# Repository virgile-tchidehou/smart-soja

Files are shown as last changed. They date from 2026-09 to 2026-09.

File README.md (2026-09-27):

<div align="center">

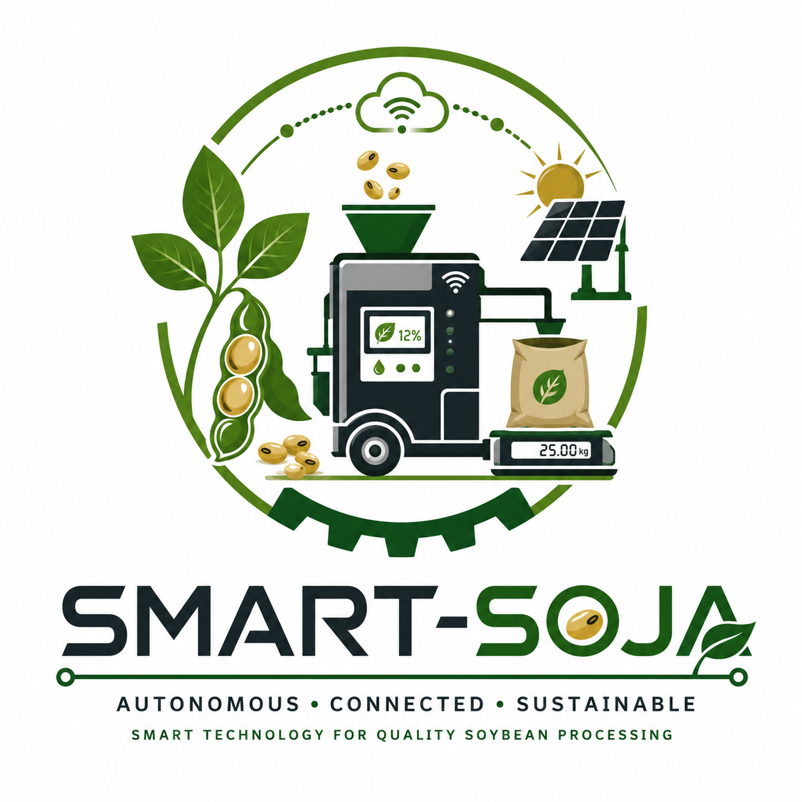
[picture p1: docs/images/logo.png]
SMART-SOJA logo


# 🌱 SMART-SOJA

### An Autonomous IoT-Based Mobile Soybean Pre-processing System














**[Documentation](#-documentation) · [Architecture](#️-system-architecture) · [Hardware](#️-hardware-overview) · [Roadmap](#-project-roadmap)**

</div>

---

SMART-SOJA is an academic engineering project co-developed by **Elisa Christelle LOKO** and **Dodji Virgile TCHIDEHOU**. It explores a mobile and connected soybean pre-processing unit designed to improve post-harvest handling in rural environments.

The prototype combines embedded systems, industrial automation, IoT technologies and an off-grid solar/battery architecture. At its current stage, the project is a **functional proof of concept**: the main sensing, actuation, drying and IoT subsystems have been validated individually or in partial integration, while full-cycle validation under a real 2–5 kg load and final HX711 weighing integration remain future work.

<div align="center">
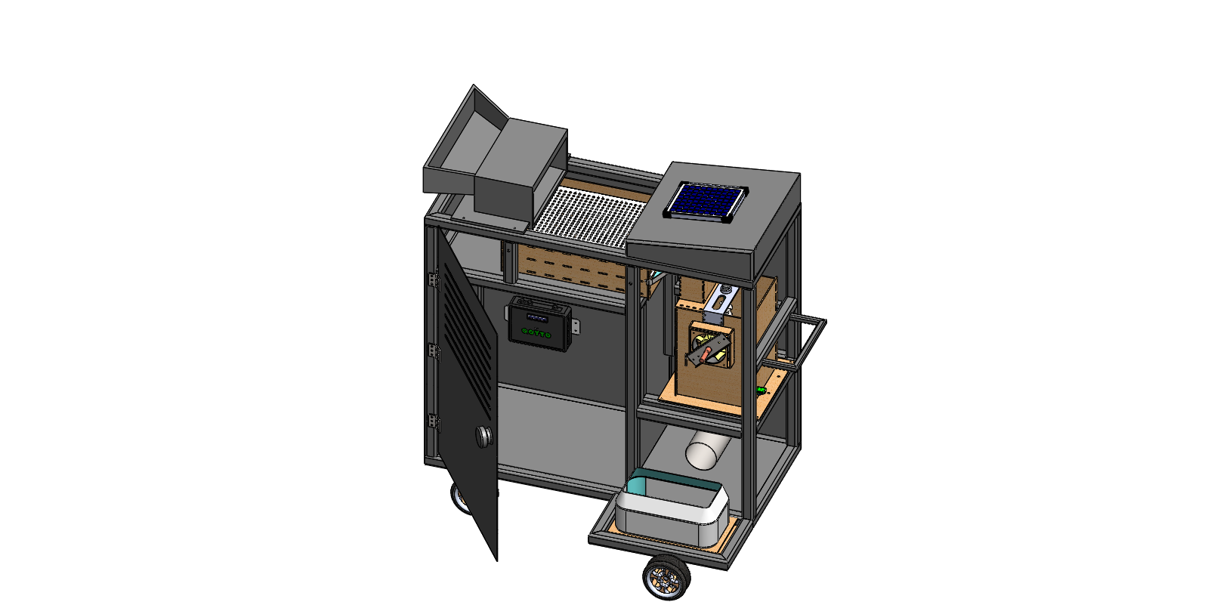
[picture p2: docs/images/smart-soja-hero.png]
SMART-SOJA prototype — assembled 3D view

</div>

---

## 📖 Table of Contents

- Overview
- The Problem
- Objectives
- Key Features
- System Architecture
- Hardware Overview
- Software Architecture
- Technology Stack
- Repository Structure
- Documentation
- Roadmap
- Future Improvements
- Project Team
- License

---

# 📌 Overview

Soybean production is rapidly increasing across Africa, particularly in Benin. However, post-harvest losses caused by inadequate cleaning, excessive moisture and poor traceability continue to reduce product quality and market value.

SMART-SOJA addresses these challenges by providing a mobile cyber-physical system capable of:

- Cleaning soybean grains through a vibrating sieve mechanism
- Measuring grain moisture at two points
- Controlling an active drying subsystem
- Supporting final batch weighing through an HX711-based subsystem *(final integration pending)*
- Recording production data locally
- Synchronizing traceability data through MQTT

The project integrates mechanical engineering, embedded electronics, industrial automation and cloud connectivity into a single modular platform.

---

# ❗ The Problem

Smallholder farmers often face several challenges:

- High post-harvest losses
- Non-uniform drying
- Manual quality control
- Lack of digital traceability
- Limited access to electricity

SMART-SOJA was designed to provide an affordable and intelligent solution adapted to rural environments.

---

# 🎯 Objectives

The project aims to:

- automate soybean pre-processing;
- improve grain quality before storage;
- reduce moisture-related losses;
- provide digital traceability;
- support off-grid operation through a solar/battery power architecture;
- support smart agriculture initiatives.

---

# ✨ Key Features

- 🌱 Mobile modular platform
- 📡 IoT connectivity using MQTT
- ⚙️ Embedded control with ESP32
- ☀️ Solar/battery off-grid power architecture
- 💧 Dual moisture sensing
- 🔥 Active drying control
- ⚖️ HX711-based weighing subsystem *(final integration pending)*
- 💾 Offline data logging (MicroSD)
- ☁️ Cloud synchronization
- 📊 Real-time monitoring
- 🧠 FreeRTOS multitasking architecture
- 🔄 GRAFCET-based sequential control

---

# 🏗️ System Architecture

SMART-SOJA is composed of six major subsystems:

## Mechanical System

- Modular chassis
- Cleaning mechanism
- Drying chamber
- Weighing module
- Mobile structure

## Embedded Electronics

- ESP32 microcontroller
- Sensors
- Power electronics
- Human-Machine Interface

## Energy System

- Solar panel
- Battery
- Charging controller
- DC converters

## Control System

- FreeRTOS scheduler
- GRAFCET automation
- Safety management

## IoT Layer

- MQTT communication
- JSON data exchange
- Cloud synchronization
- Store-and-Forward mechanism

## Traceability Layer

- Batch identification
- Local storage
- Cloud database
- Digital production records

---

# ⚙️ Hardware Overview

Main components include:

- ESP32 DevKit
- Capacitive moisture sensors
- HX711 load cell module
- Servo motors
- DC geared motors
- MOSFET power drivers
- LCD I2C display
- MicroSD module
- Solar panel
- Battery system

---

# 💻 Software Architecture

The embedded firmware is based on FreeRTOS.

Main software modules:

- Safety Task
- Control Task
- Sensor Task
- Actuator Task
- LCD Task
- MQTT Task

The control logic is modeled using a two-level GRAFCET to ensure deterministic and reliable operation.

---

# 🛠️ Technology Stack

## Embedded

- ESP32
- FreeRTOS
- Arduino IDE / Arduino Framework

## IoT

- MQTT (HiveMQ broker)
- JSON
- Wi-Fi

## Cloud & Web

- Node.js / Express (MQTT-to-cloud bridge API)
- Firebase (Firestore, Realtime Database, Hosting)
- Vite.js / Vanilla JavaScript (dashboard SPA)

## Mechanical

- SolidWorks

## Electronics

- KiCad

---

# 📁 Repository Structure

```text
smart-soja/
│
├── README.md                  # Présentation du projet
├── LICENSE
├── .gitignore
│
├── docs/                       # Documentation technique (9 chapitres + images)
│   ├── 01-project-overview.md
│   ├── 02-system-architecture.md
│   ├── 03-hardware-design.md
│   ├── 04-mechanical-design.md
│   ├── 05-software-architecture.md
│   ├── 06-energy-system.md
│   ├── 07-testing-validation.md
│   ├── 08-results.md
│   ├── 09-future-improvements.md
│   └── images/
│
├── firmware/
│   └── esp32/
│       └── src/                # Firmware ESP32 (FreeRTOS, GRAFCET)
│
├── hardware/                   # Conception électronique (KiCad)
│   ├── conception.md
│   ├── pcb/circuit_smart-soja/ # Projet KiCad complet (sch, pcb, gerbers, BOM)
│   ├── schematics/              # Exports PDF/SVG du schéma
│   ├── bom/                     # Nomenclature des composants
│   ├── wiring/                  # Schémas de brochage (pinout) des capteurs/modules
│   └── datasheets/               # Références vers les fiches techniques constructeur
│
├── mechanical/                 # Conception mécanique (SolidWorks)
│   ├── conception.md
│   ├── solidworks/
│   ├── stl/
│   ├── drawings/
│   └── renders/
│
├── cloud/
│   ├── mqtt/                   # Spécification du protocole ESP32 ↔ broker
│   ├── database/                # Documentation du schéma Firestore
│   ├── api/                     # Backend Node.js/Express (passerelle MQTT → Firebase)
│   └── dashboard/app/           # Plateforme web Vite.js (tableaux de bord)
│
├── media/                      # Photos du prototype, captures d'écran, diagrammes
│   ├── prototype/
│   ├── screenshots/
│   └── diagrams/
│
├── research/
│   └── thesis/                  # Mémoire complet (source de la documentation)
│
└── .github/
    └── ISSUE_TEMPLATE/
```

---

# 📚 Documentation

Full technical documentation lives in [`docs/`](docs/):

| Chapter | Content |
|---|---|
| [01 – Project Overview](docs/01-project-overview.md) | Context, problem statement, objectives |
| [02 – System Architecture](docs/02-system-architecture.md) | Edge / Cloud / Application layers |
| [03 – Hardware Design](docs/03-hardware-design.md) | ESP32, sensors, actuators, PCB |
| [04 – Mechanical Design](docs/04-mechanical-design.md) | Modular chassis and 4 functional blocks |
| [05 – Software Architecture](docs/05-software-architecture.md) | FreeRTOS, GRAFCET, MQTT/JSON, web dashboard |
| [06 – Energy System](docs/06-energy-system.md) | Solar/battery sizing |
| [07 – Testing & Validation](docs/07-testing-validation.md) | Unit test protocol and results |
| [08 – Results](docs/08-results.md) | Prototype outcomes, financial evaluation |
| [09 – Future Improvements](docs/09-future-improvements.md) | Validation roadmap and product evolution |

The technical documentation in this repository is derived from the academic thesis. The full thesis PDF is intentionally not distributed in the public repository; supporting figures and project material remain under [`research/thesis/`](research/thesis/).

---

# 🚀 Project Roadmap

- [x] Problem identification
- [x] Requirements analysis
- [x] Mechanical design
- [x] Electronic architecture
- [x] Embedded software
- [x] Prototype assembly and integration
- [x] Unit-level functional validation (sensors, actuators, MQTT traceability)

### Next Milestones

- [ ] Full clean + dry cycle validation under real load (2–5 kg)
- [ ] Load-cell (HX711) weighing module integration
- [ ] Field testing under real environmental conditions
- [ ] PCB redesign (multilayer)
- [ ] Mobile application
- [ ] OTA firmware updates
- [ ] AI-assisted moisture prediction
- [ ] Version 2 prototype

---

# 🌍 Future Vision

SMART-SOJA is envisioned as a scalable smart agriculture platform capable of supporting digital transformation in African agricultural value chains.

Future versions will integrate:

- Edge AI
- Predictive maintenance
- Computer vision
- Fleet management
- Remote diagnostics
- Industrial IoT deployment

---

<div align="center">

# 👥 Project Team

**Elisa Christelle LOKO** — Co-developer  
**Dodji Virgile TCHIDEHOU** — Co-developer · repository maintainer

Final-year project — Professional License in Industrial Computing & Maintenance, EGEI / UCAO-UUC, 2026.  
Academic supervisor: **Dr DIDAVI Audace**

This public repository is maintained by Dodji Virgile TCHIDEHOU and documents the team project together with the technical work contributed during its development.



</div>

---

# 📄 License

<div align="center">

This project is licensed under the [MIT License](LICENSE).

**🌱 SMART-SOJA — from the field to the factory, one certified batch at a time.**

</div>

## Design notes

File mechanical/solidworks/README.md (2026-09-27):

# SolidWorks source files

Le modèle CAO complet (assemblage final `Smart-Soja.STEP` ainsi que les pièces et sous-assemblages SolidWorks détaillés) n'est pas distribué dans ce dépôt public.

Pour consulter les rendus et vues techniques, voir [`mechanical/renders/`](../renders/) et [`mechanical/drawings/`](../drawings/), ainsi que [04-mechanical-design.md](../../docs/04-mechanical-design.md).

Pour un accès aux fichiers sources, contacter le mainteneur du dépôt — voir la section [Project Team](../../README.md#-project-team) du README.

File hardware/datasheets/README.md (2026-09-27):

# Datasheets

Aucune fiche technique constructeur n'est redistribuée dans ce dépôt (droits d'auteur des fabricants). Références des composants utilisés par SMART-SOJA :

| Composant | Fabricant / réf. | Datasheet |
|---|---|---|
| ESP32-WROOM-32 | Espressif | https://www.espressif.com/en/products/modules/esp32 |
| DHT22 (AM2302) | Aosong | https://www.adafruit.com/product/385 |
| HX711 (amplificateur cellule de charge) | Avia Semiconductor | https://www.sparkfun.com/products/13879 |
| MOSFET IRLZ44N | Infineon / Vishay | https://www.vishay.com/docs/91238/irlz44n.pdf |
| Régulateur LM2596 | Texas Instruments | https://www.ti.com/product/LM2596 |
| Servomoteur SG90 | Tower Pro | https://www.towerpro.com.tw/product/sg90-7/ |
| Moteur DC JGA25-370 | générique | voir revendeur |

Voir aussi [`hardware/wiring/`](../wiring/) pour les schémas de brochage (pinout) utilisés lors de l'intégration.

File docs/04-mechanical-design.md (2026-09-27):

# Mechanical Design

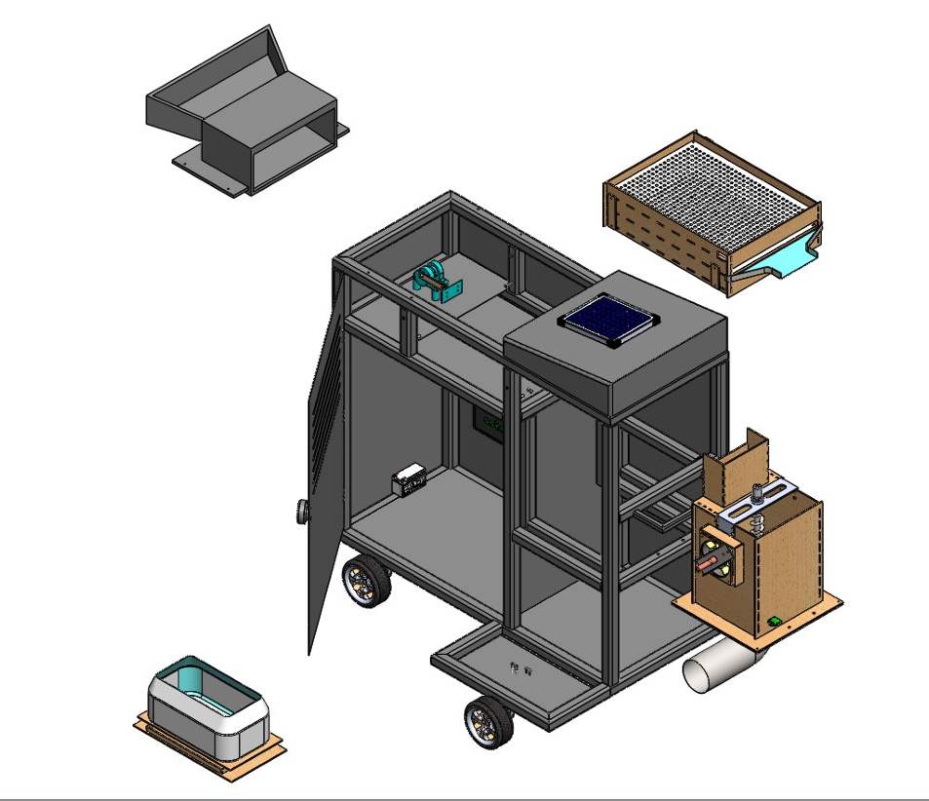
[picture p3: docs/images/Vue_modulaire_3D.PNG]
Vue modulaire 3D


Rendus et plans : [`mechanical/renders/`](../mechanical/renders/), [`mechanical/stl/`](../mechanical/stl/) (impression 3D), [`mechanical/drawings/`](../mechanical/drawings/) (découpe laser, mises en plan). Document de conception détaillé : [`mechanical/conception.md`](../mechanical/conception.md).

> Le dépôt étant public, les fichiers CAO SolidWorks (assemblage final et pièces détaillées) ne sont pas distribués ici — voir [`mechanical/solidworks/README.md`](../mechanical/solidworks/README.md) pour les obtenir sur demande.

## Architecture modulaire

La conception mécanique repose sur un **châssis porteur** (acier, tubes 30–40 mm) accueillant **quatre blocs fonctionnels amovibles**, montés sur glissières et connecteurs rapides afin de permettre une maintenance en milieu rural isolé sans démontage intégral (retrait/repose d'un bloc en moins de 15 min).

| Bloc | Fonction |
|---|---|
| **Bloc 1 — Entrée** | Trémie pyramidale à écoulement gravitaire, vanne pilotée par servomoteur SG90, capteur IR1 de présence de soja |
| **Bloc 2 — Nettoyage / tamisage** | Deux tamis inox superposés sur suspensions élastiques, moteur JGA25-370 entraînant les oscillations via poulie/tige de transmission |
| **Bloc 3 — Séchage / analyse** | Vis sans fin (brassage), ensemble ventilateur + résistance chauffante, boîtiers pour sondes capacitives Soil1/Soil2 et DHT22 |
| **Bloc 4 — Pesée / réception** | Support cellule de charge (HX711), plateau de réception finale, capteur IR2 de retrait du sac |

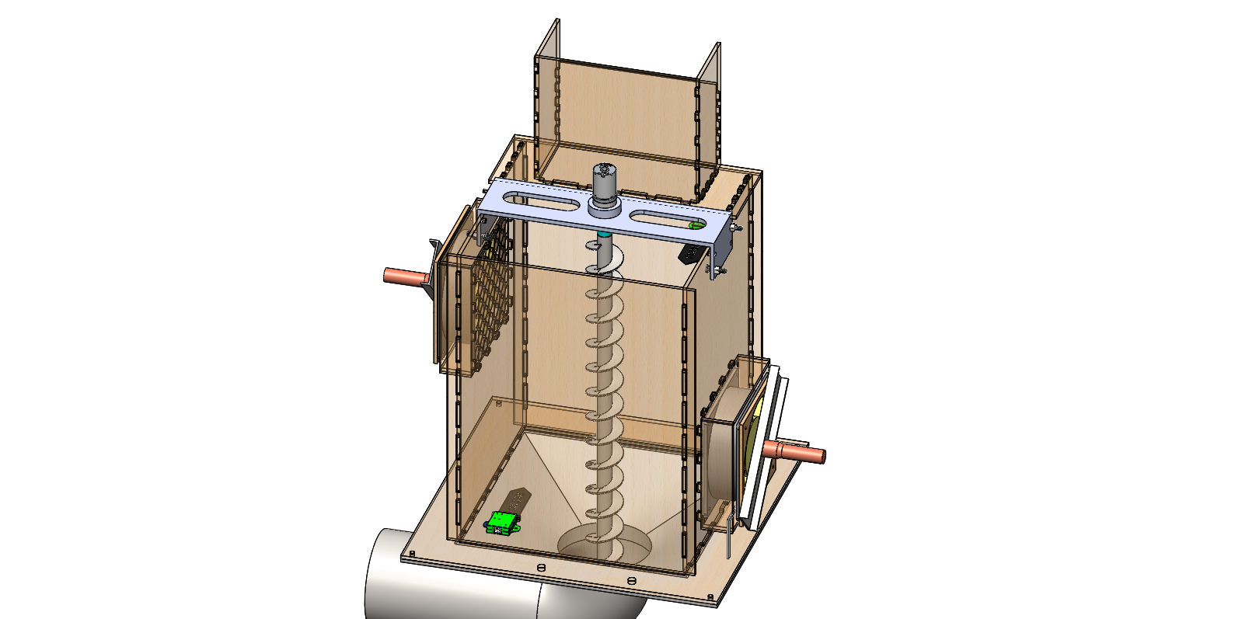
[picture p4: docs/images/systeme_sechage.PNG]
Système de séchage

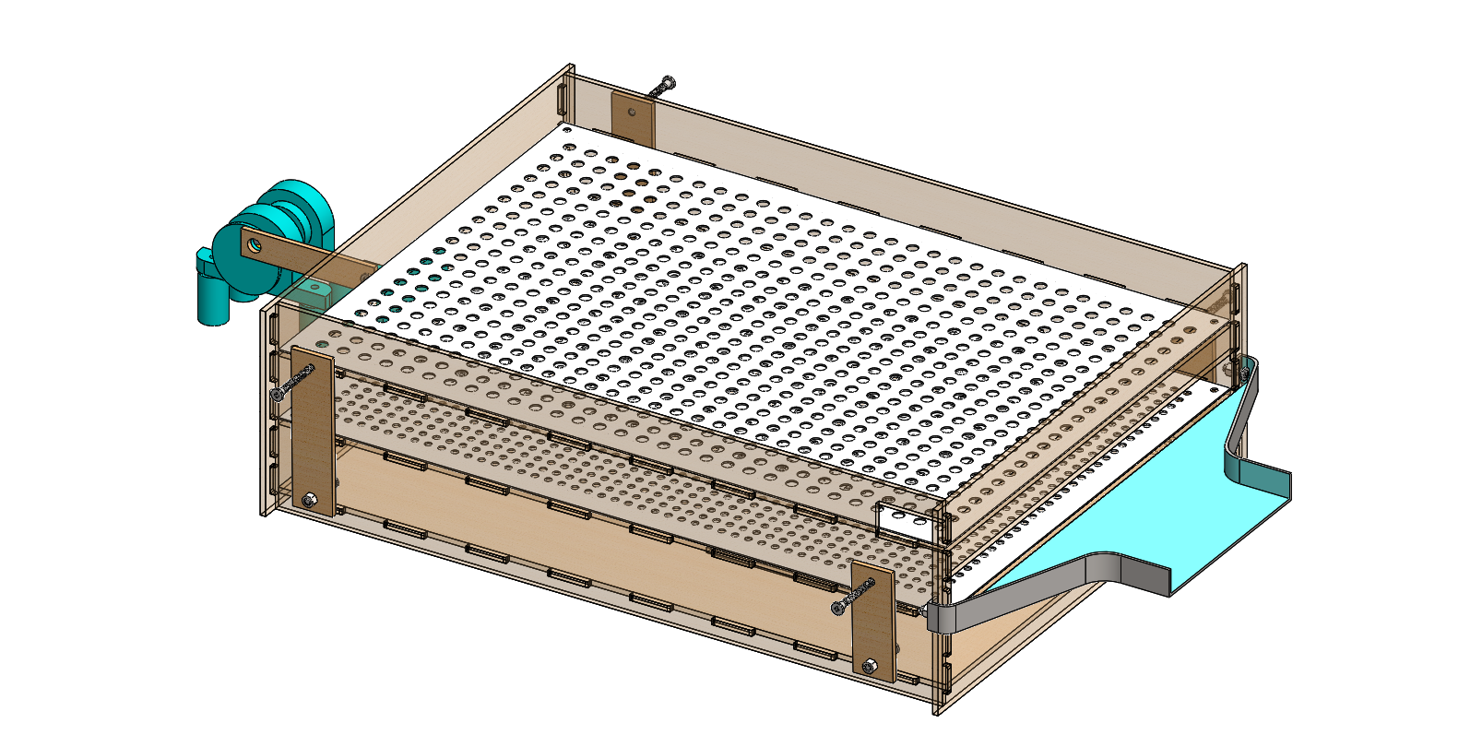
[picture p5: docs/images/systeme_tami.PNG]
Système de tamisage


## Matériaux

| Élément | Masse (kg) | Contrainte | Justification |
|---|---|---|---|
| Châssis porteur | 12,0 | Compression / haute | Acier (tubes 40 mm) : robustesse et soudabilité |
| Support tamis | 0,293 | Vibration / haute | Inox 304 : résistance à la corrosion et hygiène |
| Support capteur | 0,1 | Flexion / moyenne | PLA (impression 3D) : précision et légèreté |
| Roulettes (×4) | 2,0 | Chocs / élastique | Caoutchouc HD : absorption des vibrations |

## Outils de conception

- **SolidWorks** — modélisation 3D intégrale, simulation d'assemblage, mises en plan techniques.
- **KiCad** — conception du PCB embarqué (voir [03-hardware-design.md](03-hardware-design.md)).

## Fabrication et assemblage

Le châssis a été réalisé par découpe de panneaux de contreplaqué haute densité, aux dimensions issues de la modélisation SolidWorks, à l'atelier de **Sèmè City Open Park** (scie circulaire sur table).

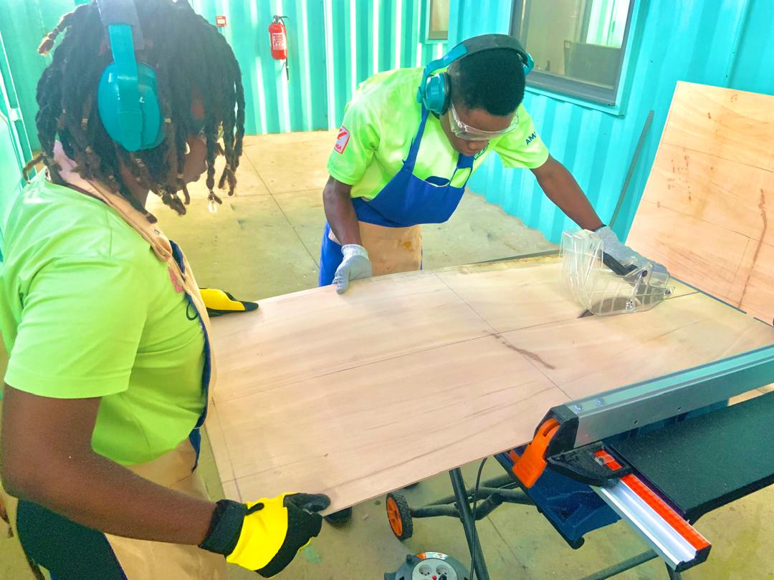
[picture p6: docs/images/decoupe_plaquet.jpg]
Découpe du contreplaqué


Le prototype physique assemblé (juin 2026) est visible ci-dessous — blocs d'alimentation, de tamisage et de séchage :

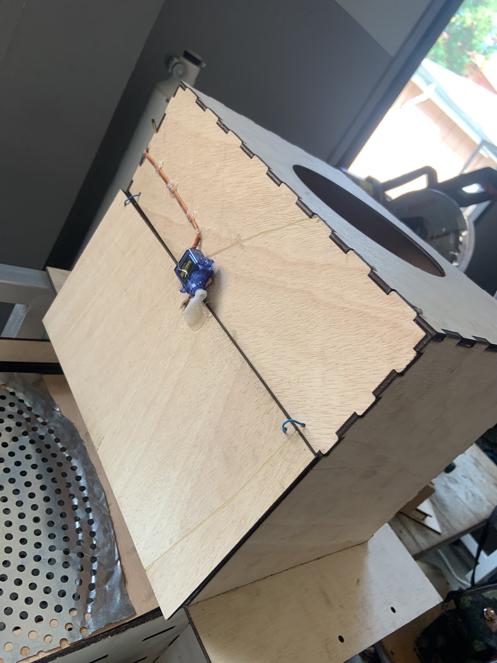
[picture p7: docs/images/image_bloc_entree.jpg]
Bloc d'alimentation

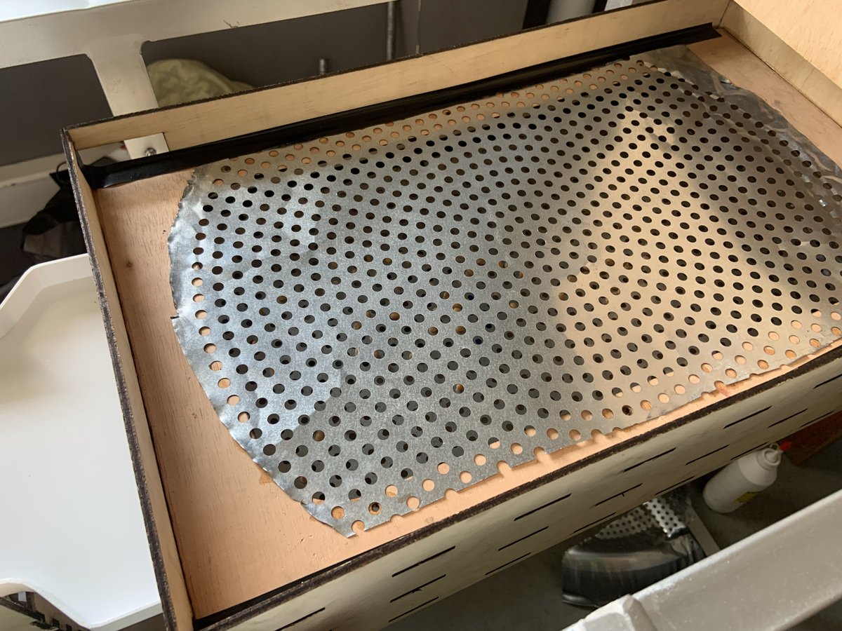
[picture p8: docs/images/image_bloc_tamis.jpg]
Bloc de tamisage

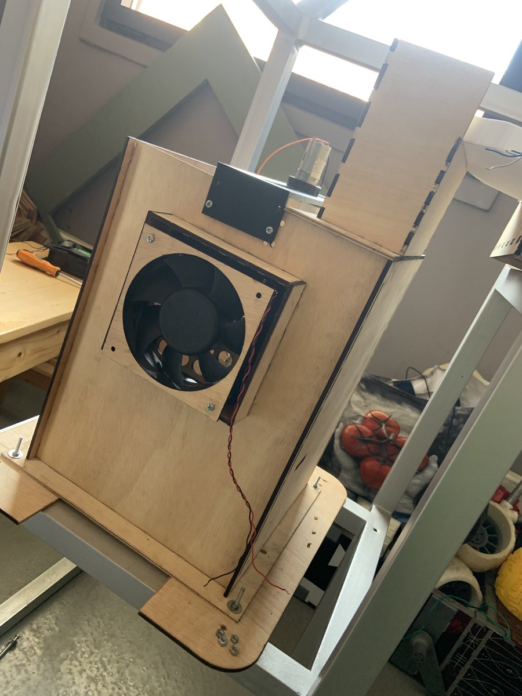
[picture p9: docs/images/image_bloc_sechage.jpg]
Bloc de séchage


## Voir aussi

- [`mechanical/drawings/`](../mechanical/drawings/) — DXF pour découpe laser, mise en plan (`Mise_en_plan_Smart-Soja.SLDDRW`)
- [`mechanical/stl/`](../mechanical/stl/) — pièces imprimables en 3D
- [07-testing-validation.md](07-testing-validation.md) — validation du tamisage et du séchage

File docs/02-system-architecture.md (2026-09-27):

# System Architecture

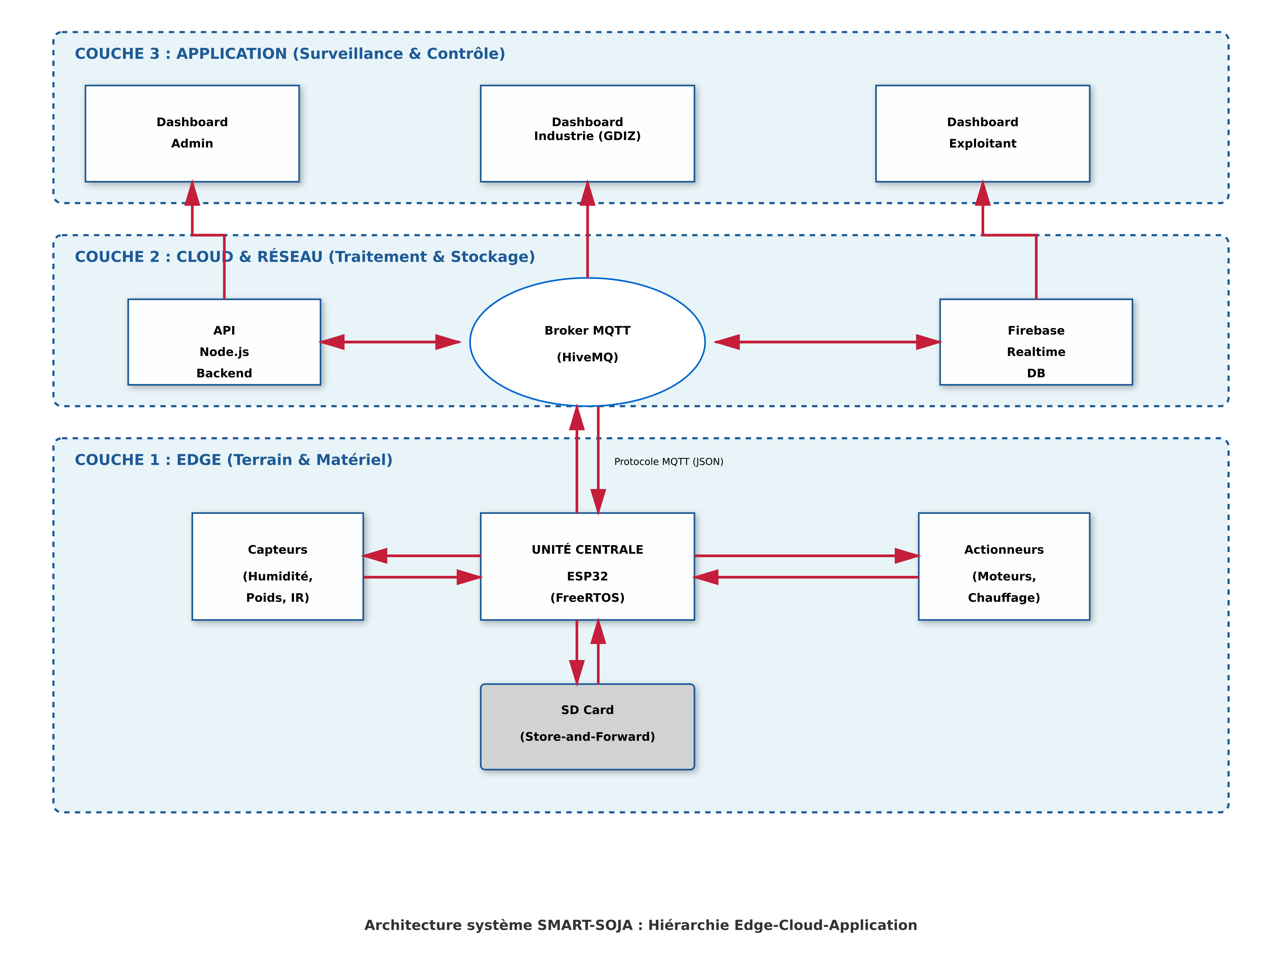
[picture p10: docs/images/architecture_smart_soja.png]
Architecture SMART-SOJA


SMART-SOJA repose sur une architecture modulaire hiérarchisée en **trois couches fonctionnelles**, garantissant un fonctionnement autonome complet en mode déconnecté tout en s'intégrant nativement dans une infrastructure Cloud de type Industrie 4.0.

## Couche Edge (terrain)

L'**ESP32** gère en temps réel :
- l'acquisition des capteurs (humidité, température, présence, poids) ;
- le pilotage des actionneurs (moteurs, résistance, ventilateur, servomoteurs) ;
- la logique de contrôle séquentiel **GRAFCET** ;
- la sécurité prioritaire (arrêt d'urgence, surchauffe).

Détails : [05-software-architecture.md](05-software-architecture.md).

## Couche Cloud

- **Broker MQTT (HiveMQ)** : réception des trames télémétrie et fin-de-lot publiées par l'ESP32.
- **API Node.js (`cloud/api/`)** : passerelle qui intercepte les messages MQTT, les valide, les enregistre dans Firebase et génère les documents de traçabilité (QR Code, PDF).
- **Firebase (Firestore + Realtime Database)** : stockage persistant des lots traités.

## Couche Application

- **Tableau de bord web (`cloud/dashboard/app/`)** : Single Page Application (Vite.js + JavaScript) avec trois profils d'accès :
  - **Exploitant** : suivi de production temps réel, contrôle manuel des actionneurs via MQTT, alertes maintenance ;
  - **Industrie (GDIZ Ready)** : validation qualité des lots entrants, graphiques humidité/température, certificats de traçabilité PDF ;
  - **Admin** : gestion de la flotte de machines et des utilisateurs.

## Résilience réseau : Store-and-Forward

En l'absence de couverture WiFi (fréquente en zone rurale), toutes les métriques sont sauvegardées localement sur carte MicroSD (SPI, FAT32) et retransmises automatiquement au broker MQTT dès la reconnexion. Ce mécanisme garantit qu'aucune donnée de traçabilité n'est perdue.

## Flux de données

```mermaid
flowchart LR
    subgraph Edge["Couche Edge (ESP32)"]
        S[Capteurs] --> C[GRAFCET / FreeRTOS]
        C --> A[Actionneurs]
        C --> SD[MicroSD - Store & Forward]
    end
    C -- JSON / MQTT --> B[Broker MQTT HiveMQ]
    B --> API[API Node.js - cloud/api]
    API --> FB[(Firebase Firestore)]
    FB --> WEB[Dashboard Web - cloud/dashboard/app]
```

## Voir aussi

- [03-hardware-design.md](03-hardware-design.md)
- [04-mechanical-design.md](04-mechanical-design.md)
- [../cloud/mqtt/ESP32_PROTOCOL.md](../cloud/mqtt/ESP32_PROTOCOL.md) — spécification détaillée des topics et payloads MQTT

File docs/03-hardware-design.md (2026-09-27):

# Hardware Design

Fichiers sources : [`hardware/pcb/circuit_smart-soja/`](../hardware/pcb/circuit_smart-soja/) (projet KiCad complet), [`hardware/bom/`](../hardware/bom/), [`hardware/schematics/`](../hardware/schematics/). Document de conception détaillé : [`hardware/conception.md`](../hardware/conception.md).

## Unité de traitement : ESP32-WROOM-32

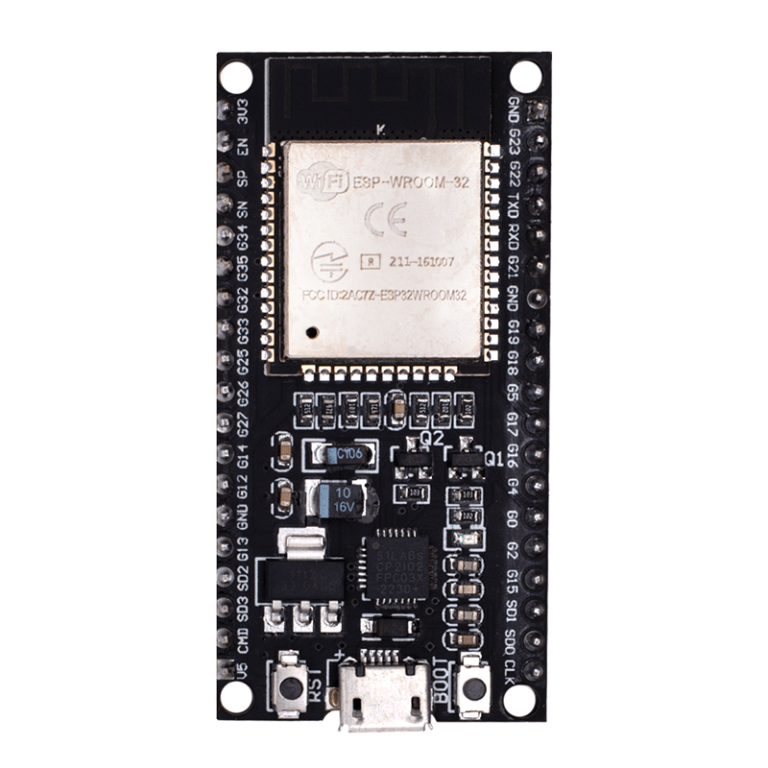
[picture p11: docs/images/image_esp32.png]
ESP32


| Caractéristique | Spécification |
|---|---|
| Microcontrôleur | Tensilica LX6 double cœur, 240 MHz |
| Alimentation | 5 V DC (microUSB) / 3,3 V DC (E/S) |
| Consommation veille | 5 µA |
| Mémoire | 520 Ko SRAM / 4 Mo Flash |
| Connectivité | Wi-Fi 802.11 b/g/n + Bluetooth 4.2 |
| GPIO | 30 broches (3× UART, 2× I2C, 3× SPI, 12× ADC, 2× DAC) |

**Justification :** l'architecture dual-core dédie un cœur au contrôle-commande temps réel (capteurs, PWM) et l'autre à la communication IoT (MQTT/WiFi), garantissant un déterminisme critique. Le brochage évite les *strapping pins* (GPIO 0, 2, 12, 15) critiques au démarrage.

## Chaîne d'acquisition (capteurs)

| Capteur | Plage / Précision | Rôle | Limites |
|---|---|---|---|
| DHT22 | 0–100 % HR / ±2 % | Humidité/température ambiante | Temps de réponse 2 s |
| Sonde capacitive (×2, Soil1/Soil2) | 0–100 % / ±5 % | Humidité des grains | Dérive thermique |
| IR réflectif (×2) | 2–30 cm / binaire | Présence trémie/sac | Sensible à la lumière ambiante |
| Cellule de charge + HX711 | 0–10 kg / ±0,1 % | Pesée finale du lot | Sensible aux vibrations |

La sonde capacitive mesure la constante diélectrique du milieu (eau ≈ 80 vs grain sec ≈ 3–5), ce qui la rend insensible à la corrosion. Deux sondes (haut/bas de la zone de séchage) permettent une double validation : le séchage ne s'arrête que si **Soil1 ET Soil2 ≤ 12 %**.

**Calibration in-situ** (ADC 12 bits, 0–4095) : point sec (H ≈ 8 %, soja étuvé) comme borne haute, point humide (H ≈ 20 %) comme borne basse, puis interpolation linéaire. Écart maximal observé face à un hygromètre de référence (Testo 608-H2) : ±5 %.

## Chaîne d'action (actionneurs)

| Actionneur | Puissance / Courant | Rôle |
|---|---|---|
| Moteurs JGA25-370 (×2) | 3 W / 0,5 A (max 1,2 A) | Tamisage, vis sans fin |
| Servo SG90 (×2) | 1,5 W / 0,1–0,5 A | Vanne trémie |
| Résistance chauffante (×2) | 12 W / 1 A | Séchage |
| Ventilateur DC (×2) | 1,8 W / 0,15 A | Circulation d'air |
| MOSFET IRLZ44N (×4) | *Logic level*, 47 A max, R<sub>DSon</sub> 0,022 Ω | Commutation 12 V depuis GPIO 3,3 V |

Le MOSFET **IRLZ44N** est retenu car il se sature directement avec les 3,3 V de l'ESP32 (contrairement aux MOSFET standards qui exigent 10 V de grille).

## Interfaces homme-machine et traçabilité locale

| Périphérique | Protocole | Rôle |
|---|---|---|
| LCD 16×2 | I2C | Affichage temps réel |
| Lecteur MicroSD | SPI | Store-and-Forward |
| Potentiomètres ×2 | ADC 12 bits | Réglage vitesse moteurs |
| Boutons ON/OFF | GPIO pull-up | Démarrage/arrêt sécurisé |
| LEDs + buzzer | Digital/PWM | Signalisation d'état |

## Circuit imprimé (PCB)

Le circuit est segmenté en cinq zones fonctionnelles pour limiter les interférences électromagnétiques entre signaux de puissance et de commande :

1. **Zone alimentation** — régulateur Buck LM2596 (12 V → 5 V/2 A) ; logique 3,3 V via le régulateur interne de l'ESP32.
2. **Zone ESP32** — affectation des broches optimisée pour éviter les strapping pins.
3. **Zone puissance** — chaque canal MOSFET IRLZ44N intègre une résistance de grille 220 Ω, un pull-down 10 kΩ, et une diode de roue libre 1N5408 contre les retours inductifs.
4. **Zone acquisition** — signaux analogiques (sondes capacitives sur GPIO 36/39) et numériques (HX711 sur GPIO 25, DHT22, IR sur GPIO 32/33).
5. **Zone IHM** — bus I2C (LCD), bus SPI (SD), signaux PWM (buzzer, servo, boutons).

Routage sur **une seule couche** (face inférieure) avec pistes de puissance ≥ 1 mm et plan de masse (ground pour) pour simplifier la fabrication du prototype. La modélisation 3D a permis de valider l'absence de collision mécanique avant fabrication.

Fichiers disponibles dans [`hardware/pcb/circuit_smart-soja/`](../hardware/pcb/circuit_smart-soja/) : schéma (`.kicad_sch`), routage (`.kicad_pcb`), modèle 3D (`.step`), gerbers de fabrication (`gerber/`), export DFM et nomenclature (`bom/`).

## Boîtier électronique

Boîtier imprimé en 3D (PLA) hébergeant le PCB, source CAO dans [`mechanical/solidworks/boitier_3D/`](../mechanical/solidworks/boitier_3D/).

## Voir aussi

- [02-system-architecture.md](02-system-architecture.md)
- [06-energy-system.md](06-energy-system.md) — bilan de puissance complet
- [../hardware/bom/](../hardware/bom/) — nomenclature des composants et coûts

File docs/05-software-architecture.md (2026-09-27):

# Software Architecture

Firmware source : [`firmware/esp32/src/Code_Esp32_Smart-Soja.ino`](../firmware/esp32/src/Code_Esp32_Smart-Soja.ino). Plateforme web : [`cloud/dashboard/app/`](../cloud/dashboard/app/). API/passerelle MQTT : [`cloud/api/`](../cloud/api/).

## Firmware embarqué : FreeRTOS sur ESP32

Le firmware implémente **6 tâches FreeRTOS**, communiquant via 5 files de messages (queues) pour un découplage sans conditions de course. Les tâches de sécurité préemptent systématiquement toutes les autres.

| Tâche | Priorité | Cycle | Fonction |
|---|---|---|---|
| `Task_Safety` | 4 (max) | 10 ms | Arrêt d'urgence, surchauffe, timeout — réponse < 10 ms |
| `Task_Control` | 3 (haute) | 50 ms | Automate GRAFCET, transitions d'états |
| `Task_Sensing` | 2 (moy.) | 100 ms | Acquisition DHT22, Soil1/2, HX711 avec filtrage passe-bas |
| `Task_Actuators` | 2 (moy.) | 50 ms | Pilotage PWM moteurs, servo, LEDs |
| `Task_LCD` | 1 (faible) | 200 ms | Affichage I2C + lecture potentiomètres |
| `Task_MQTT` | 1 (faible) | 500 ms | Transmission JSON, Store-and-Forward sur SD si déconnecté |

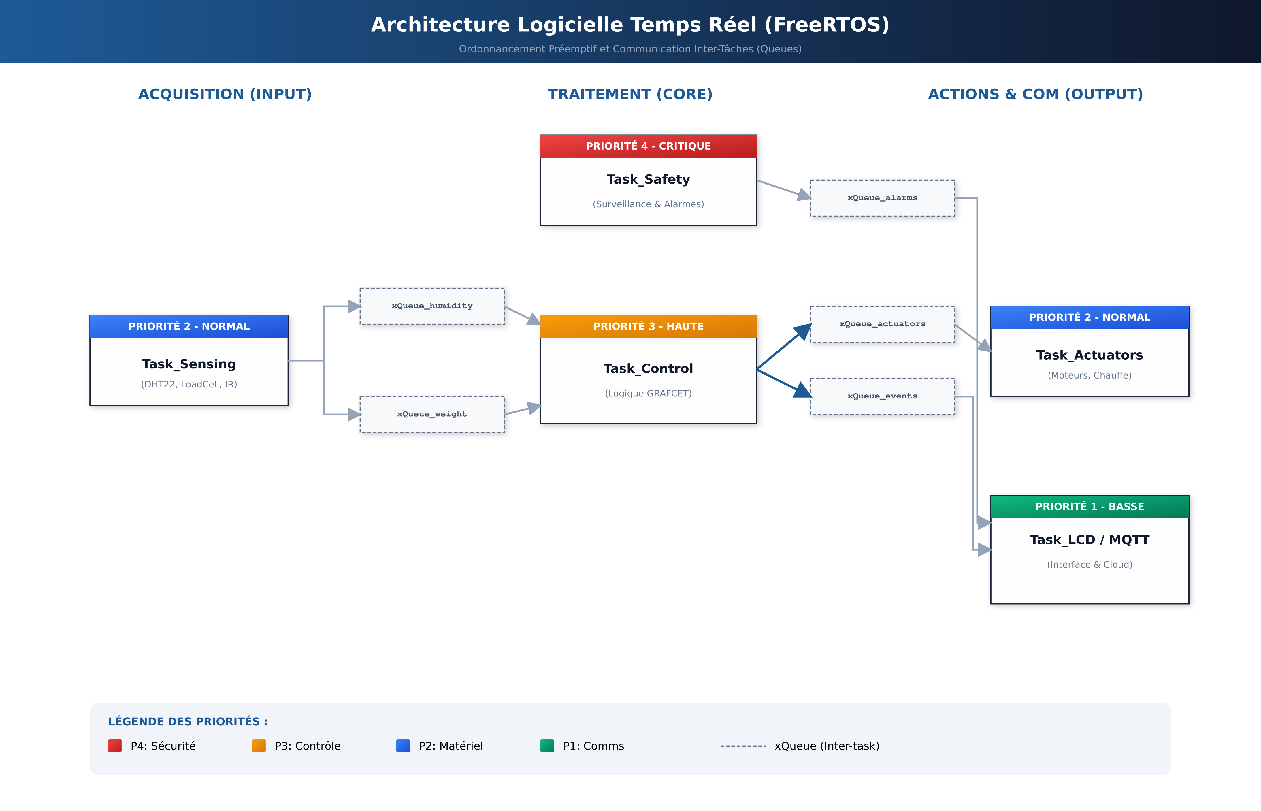
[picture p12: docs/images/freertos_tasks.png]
Diagramme de synchronisation FreeRTOS

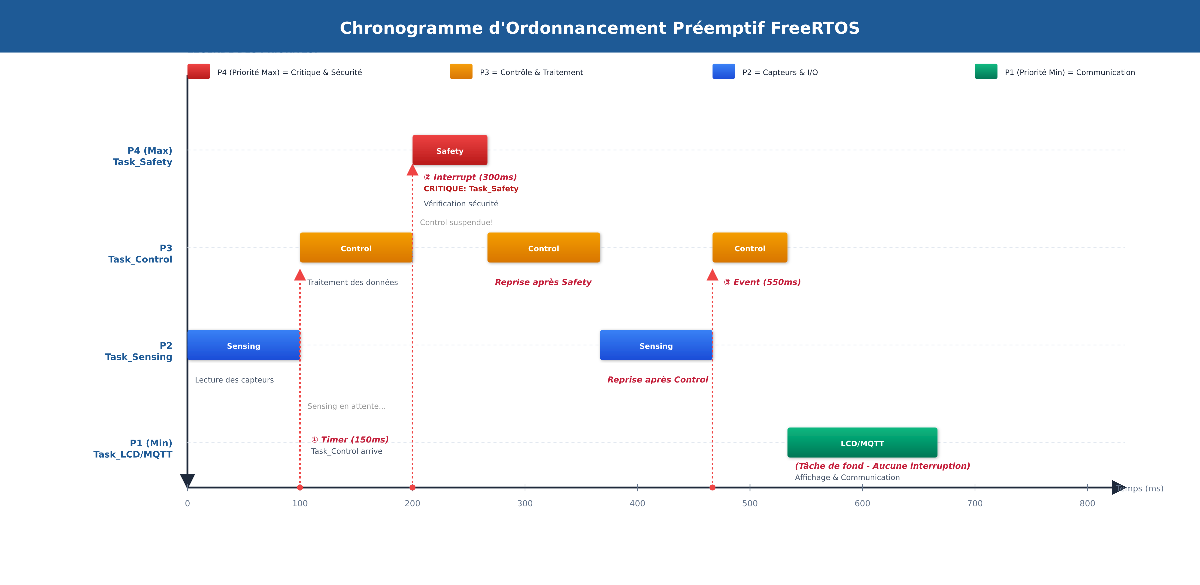
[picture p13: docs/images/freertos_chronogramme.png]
Chronogramme d'ordonnancement préemptif


Trois principes gouvernent l'ordonnancement : **préemption** (une tâche prioritaire suspend immédiatement la tâche courante), **reprise automatique** (le contexte suspendu est restauré tel quel) et **gestion des priorités** (les tâches faibles ne s'exécutent que si aucune tâche prioritaire n'est prête).

## Automatisme séquentiel : GRAFCET

Le cycle de traitement est modélisé en **GRAFCET à deux niveaux** :

- **Niveau 1 (fonctionnel)** — préparation (vérification trémie + sac) → traitement (nettoyage puis analyse d'humidité, séchage itératif si nécessaire) → clôture (pesée, enregistrement, attente de retrait du sac).
- **Niveau 2 (technologique)** — traduction en E/S ESP32 : capteurs IR1/IR2 et sondes capacitives en entrée ; servomoteurs (PWM) et MOSFETs de puissance en sortie.

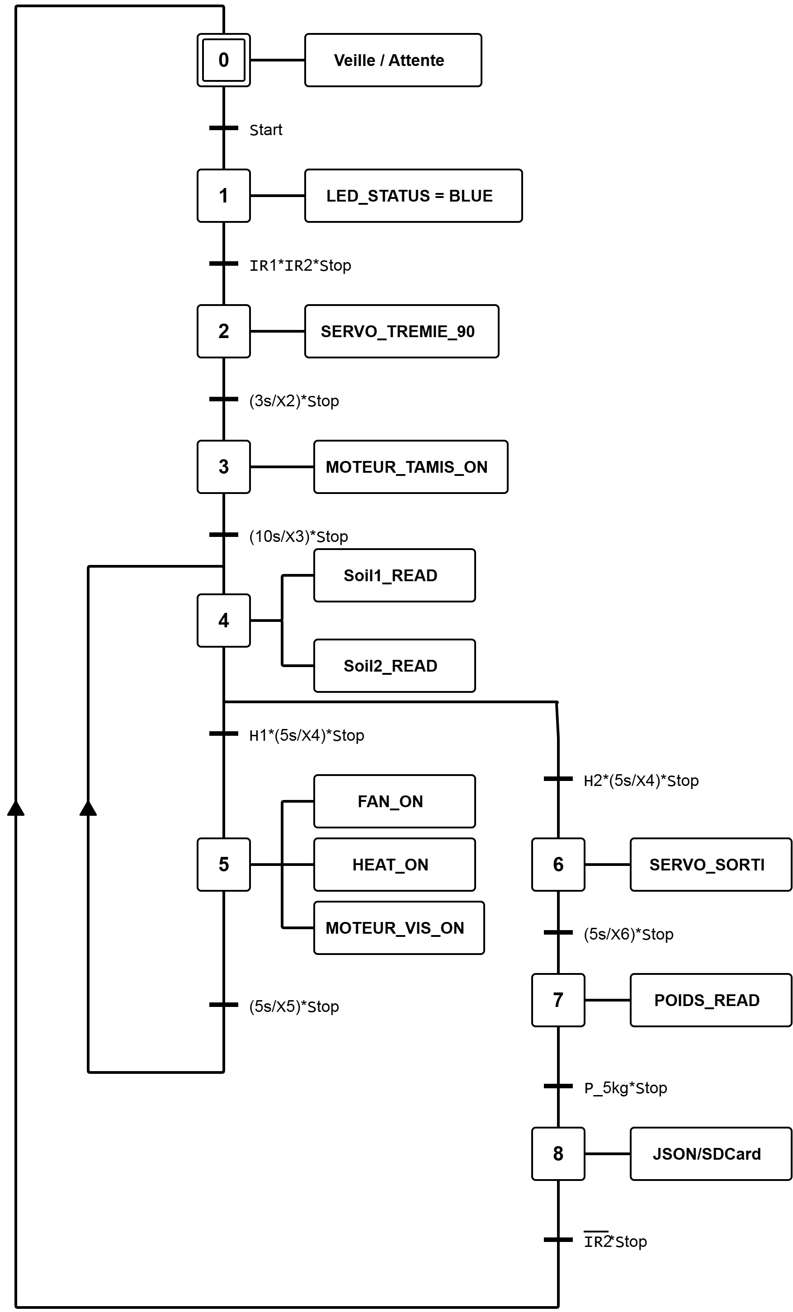
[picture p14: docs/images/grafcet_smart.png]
GRAFCET du système


**Logique de cycle :**
- **Saut de séquence** : si le soja est déjà sec à l'analyse initiale, l'étape de séchage est court-circuitée (économie d'énergie).
- **Reprise de séquence** : rebouclage systématique vers l'analyse après chaque phase de séchage.
- **Double validation de l'humidité** : l'ensachage n'est autorisé que si Soil1 **ET** Soil2 confirment individuellement H ≤ 12 %.
- **Sûreté de fonctionnement** : une évolution parallèle surveille en permanence le bouton d'arrêt d'urgence, capable d'interrompre le cycle à tout instant.

## Traçabilité numérique : MQTT + JSON

Deux types de trames sont publiés (voir [`cloud/mqtt/ESP32_PROTOCOL.md`](../cloud/mqtt/ESP32_PROTOCOL.md) pour la spécification complète) :

**Télémétrie périodique** (toutes les 5 s, topic `smart-soja/telemetry/{unitId}`) :
```json
{
  "unitId": "SS-000110",
  "timestamp": 1716633600000,
  "humidity": 12.5,
  "temperature": 31.8,
  "weight": 42.3,
  "ir1": true,
  "ir2": false,
  "mode": "auto",
  "step": 3,
  "alarm": false,
  "controls": {
    "alimentation": false,
    "tamis": true,
    "ventilateur": false,
    "chauffage": true,
    "vis_soja": true,
    "servo_vanne": false
  },
  "battery": 95
}
```

**Passeport numérique de fin de lot** (topic `smart-soja/lot_completed/{unitId}`) :
```json
{
  "unitId": "SS-000110",
  "timestamp": 1716633780000,
  "lotId": "LOT-TEST-002",
  "duration_ms": 180000,
  "weight_processed": 5000,
  "humidity_avg": 10.8,
  "temperature_avg": 31.8,
  "steps_completed": 12,
  "quality_score": 95
}
```

En cas de perte de connexion, ces trames sont archivées sur la carte MicroSD (format JSON) et renvoyées automatiquement dès le rétablissement du signal.

## Plateforme web (`cloud/dashboard/app/`)

Single Page Application développée en **Vite.js + JavaScript (Vanilla JS)**, synchronisée en temps réel avec Firebase.

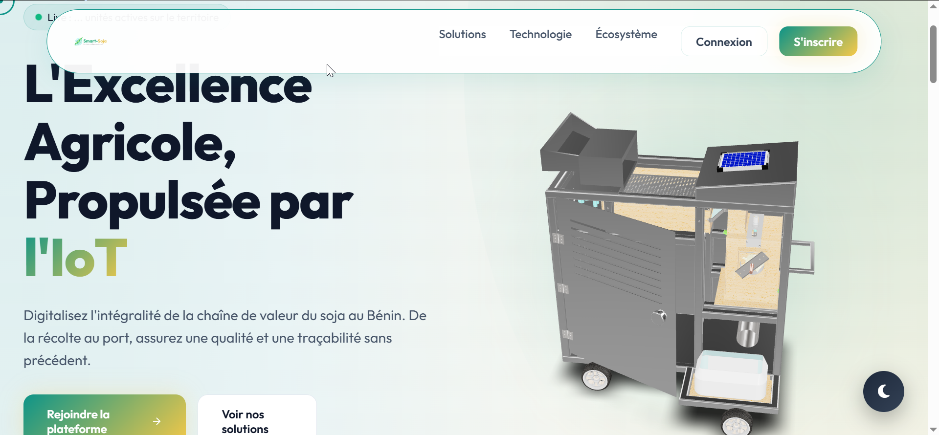
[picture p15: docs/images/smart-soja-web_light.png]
Interface claire

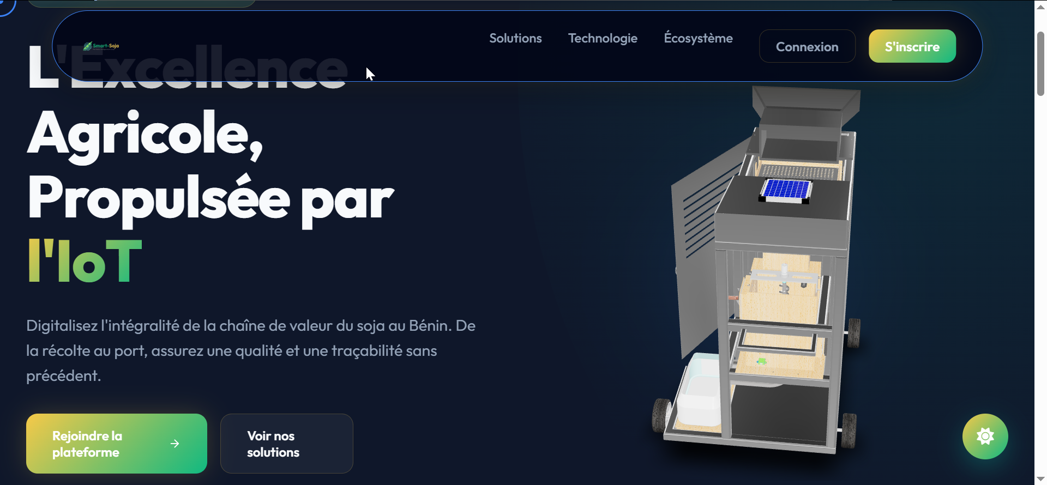
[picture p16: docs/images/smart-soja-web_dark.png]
Interface sombre


**Pipeline de données :**
1. L'ESP32 publie les trames JSON via MQTT.
2. Le serveur `cloud/api/` (Node.js) intercepte, valide et persiste les messages dans Firebase.
3. Le dashboard se synchronise automatiquement avec Firebase (pas de rafraîchissement manuel).

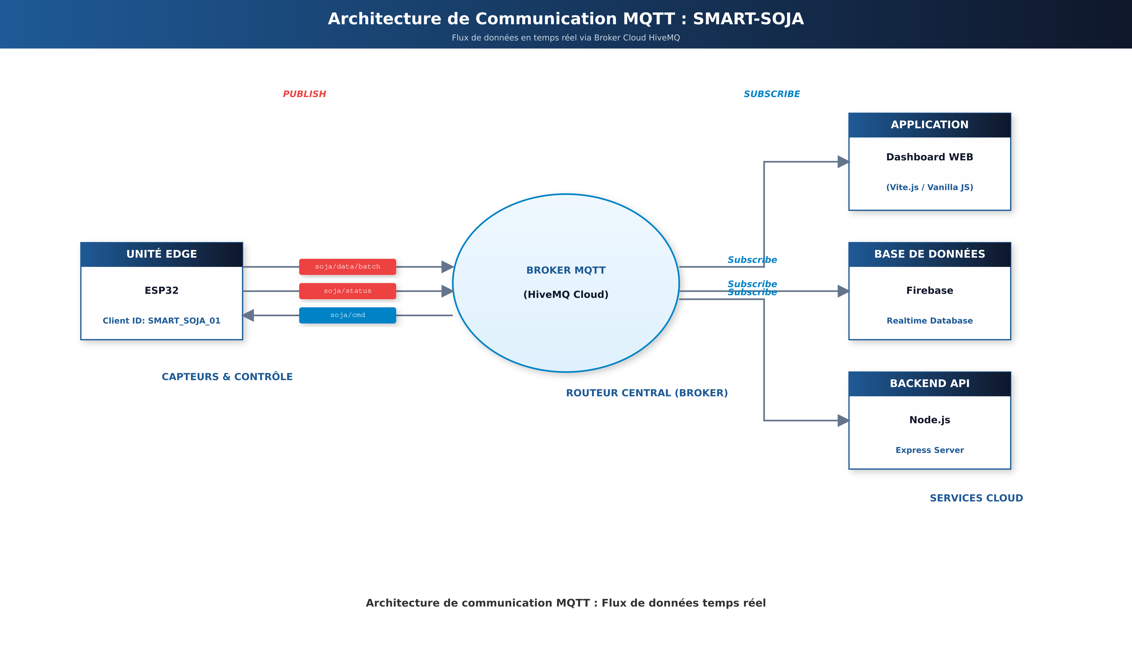
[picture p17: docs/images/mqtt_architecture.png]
Architecture MQTT


**Trois profils :** Exploitant (suivi + contrôle manuel), Industrie GDIZ Ready (validation qualité + certificats PDF), Admin (flotte + utilisateurs).

## Outils de développement

- **Arduino IDE** — firmware ESP32.
- **VS Code** — dashboard web (HTML/JS), gestion Git.

## Voir aussi

- [02-system-architecture.md](02-system-architecture.md)
- [07-testing-validation.md](07-testing-validation.md) — validation de la transmission MQTT

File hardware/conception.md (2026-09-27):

# Documentation Technique Approfondie : Électronique SMART-SOJA

Ce document constitue le dossier technique complet de la partie électronique du système **SMART-SOJA**. Il est conçu pour servir de référence pour le chapitre "Conception et Réalisation" de votre mémoire.

---

## 1. Philosophie de Conception

La conception matérielle repose sur trois piliers :

1. **Modularité** : Séparation des fonctions (Puissance, Acquisition, Traitement).
2. **Robustesse** : Utilisation de composants industriels (MOSFETs, Diodes de puissance) et protection contre les environnements ruraux.
3. **Fiabilité** : Passage d'un prototypage sur plaque d'essai à un **Circuit Imprimé (PCB)** dédié pour éliminer les faux contacts.

---

## 2. Unité de Traitement et Gestion des GPIO

Le cœur du système est un **ESP32-DEVKITC-32E**. Le choix des broches a été méticuleusement effectué pour éviter les conflits avec les "strapping pins" du microcontrôleur.

### 2.1 Tableau d'Affectation des Broches (Pinout)

| Groupe | Broche ESP32 | Fonction | Signal |
| :--- | :--- | :--- | :--- |
| **Capteurs** | GPIO 32 | Capteur IR Entrée (IR1) | Digital (High/Low) |
| | GPIO 33 | Capteur IR Sac (IR2) | Digital (High/Low) |
| | GPIO 36 (VP) | Sonde Humidité 1 (Soil1) | Analogique (ADC) |
| | GPIO 39 (VN) | Sonde Humidité 2 (Soil2) | Analogique (ADC) |
| | GPIO 25 | Capteur Temp/Hum (DHT22) | Série (1-Wire) |
| | GPIO 4 / 16  | Module Pesée HX711 (DT/SCK)| Série (DT / SCK) |
| | GPIO 35 / 34 | Potentiomètres Tamis/Vis | Analogique (ADC) |
| **Actionneurs** | GPIO 26 | Servo-moteur Trémie (SG90) | PWM (5V) |
| | GPIO 2 | Servo-moteur Vanne (SG90)  | PWM (5V) |
| | GPIO 14 | Moteur Tamis (vibration) | PWM (12V) |
| | GPIO 12 | Vis sans fin (brassage) | PWM (12V) |
| | GPIO 13 | Ventilateur 12V | Digital (12V) |
| | GPIO 27 | Résistance Chauffe | PWM (12V) |
| | GPIO 17 | Buzzer | Digital (5V) |
| **Interface** | GPIO 15 | Bouton Start (ON/OFF) | Digital Input |
| | GPIO 0 | Arrêt d'Urgence | Digital (Pull-up)  |
| | Bus I2C | Afficheur LCD 16x2 | SDA (21) / SCL (22)|

---

## 3. Schéma Électrique : Blocs Fonctionnels

Le schéma est segmenté en zones critiques pour assurer l'intégrité des signaux.

### 3.1 Zone Alimentation et Régulation

* **Entrée 12V DC** : Alimentation directe des moteurs et de la chauffe.
* **Protection** : Fusible **5A** et condensateurs de filtrage (470µF) pour absorber les appels de courant.
* **Conversion** : Module **LM2596** (Régulateur Buck) réglé sur **5V** pour alimenter les composants logiques et le rétroéclairage LCD.

### 3.2 Zone de Puissance (Commutation)

* **Composant** : MOSFET **IRLZ44N**.
* **Justification** : Choisi pour sa faible résistance à l'état passant ($R_{DS(on)}$) et sa capacité à être piloté directement en 3.3V (Logic Level).
* **Protections** :
  * Résistance de grille de **220Ω** pour protéger l'ESP32.
  * Résistance de rappel de **10kΩ** pour éviter les démarrages intempestifs.
  * Diodes **1N5408** pour la protection contre les courants de retour (Inductive Kickback).

---

## 4. Conception du Circuit Imprimé (PCB)

La carte a été conçue sous **KiCad** avec une approche "Double Face" (Top & Bottom).

* **Pistes de Puissance** : Largeur de **1.0 mm** minimum pour les lignes 12V et Masse.
* **Plan de Masse** : Un plan de masse étendu sur les deux faces permet de dissiper la chaleur et de réduire les parasites électromagnétiques.
* **Connectique** : Borniers à vis (**T-Blocks**) pour une fixation solide des câbles moteurs.

---

## 5. Bilan Énergétique et Dimensionnement

Basé sur les mesures réelles du prototype :

### 5.1 Consommation du Système

* **Logique (ESP32 + LCD + Sensors)** : ~1.85 W.
* **Mécanique (Moteurs + Servos)** : ~9.30 W.
* **Séchage (Résistance 6Ω)** : ~24 W.
* **Total en Charge Maximale** : **~35 W**.

### 5.2 Source de Production : Panneau Solaire 50W

Le panneau de **50W** est dimensionné pour couvrir la consommation maximale (~35W) tout en rechargeant la batterie en période d'ensoleillement direct. Une batterie **LiFePO4 de 20Ah** est recommandée pour assurer une autonomie de 4 heures en mode traitement intensif.

---

## 6. Liste des Fichiers de Fabrication (Gerber)

Le dossier `gerber/` contient les fichiers nécessaires à la fabrication industrielle :

* `F_Cu / B_Cu` : Tracés des pistes cuivre (Faces Avant/Arrière).
* `F_Silkscreen` : Sérigraphie pour le repérage des composants.
* `PTH / NPTH` : Fichiers de perçage pour les composants traversants.
* `Edge_Cuts` : Contour physique de la carte.

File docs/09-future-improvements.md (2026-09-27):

# Future Improvements

Le prototype SMART-SOJA est, à ce stade (juin 2026), une **preuve de concept fonctionnelle** : chaque module a été validé individuellement (voir [07-testing-validation.md](07-testing-validation.md)), mais des étapes restent nécessaires avant un déploiement en conditions réelles.

## Axe 1 — Validation en charge réelle

- Cycles complets nettoyage + séchage avec charges progressives : 100 g, 500 g, 2 kg, 5 kg, en laboratoire.
- Mesure du temps de séchage nécessaire pour atteindre la cible d'humidité (< 12 %).
- Mesure du taux de pureté du soja après tamisage.
- Vérification de la stabilité des paramètres (température, humidité) dans la chambre de séchage.
- Validation de l'autonomie batterie en fonctionnement continu (voir [06-energy-system.md](06-energy-system.md)).

## Axe 2 — Intégration et robustesse mécanique

- Finalisation de l'intégration du module de pesée (cellule de charge + HX711), avec étalonnage sur la plage 0–5 kg conforme au cahier des charges (FP4, ±0,1 %).
- Validation de la résistance du cadre de tamisage aux vibrations prolongées (> 30 min) et identification des renforts structurels nécessaires.
- Documentation du protocole de maintenance préventive (nettoyage des tamis, inspection des connexions, étalonnage périodique des capteurs).

## Axe 3 — Campagne terrain

- Tests en conditions réelles sur des sites de collecte, avec mesures comparatives par rapport à des équipements de référence certifiés.
- Validation en conditions environnementales extrêmes : température > 30 °C, humidité relative > 70 %, exposition à la poussière.

## Pistes d'évolution du produit

Au-delà des travaux de validation immédiats, plusieurs axes de développement produit sont envisagés :

- PCB v2 (routage multicouche, réduction du prototype vers une carte industrialisable).
- Application mobile pour l'exploitant (en complément du dashboard web).
- Mises à jour firmware OTA (Over-The-Air) pour la maintenance à distance de la flotte.
- Prédiction d'humidité assistée par IA à partir de l'historique des lots.
- Déploiement industriel à plus grande échelle (fleet management multi-unités pour coopératives).

## Conclusion

Le projet SMART-SOJA démontre qu'une démarche d'ingénierie mécatronique rigoureuse — associée aux technologies IoT et à une traçabilité numérique robuste — peut contribuer à améliorer la qualité des produits agricoles à chaque étape de la chaîne de valeur béninoise, de la parcelle à l'usine. Les figures et éléments de travail issus du mémoire sont conservés dans [`research/thesis/`](../research/thesis/). Le PDF complet n'est pas distribué dans le dépôt public.

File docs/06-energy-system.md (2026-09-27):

# Energy System

Pour garantir un fonctionnement ininterrompu en milieu rural hors réseau, SMART-SOJA repose sur une alimentation photovoltaïque autonome, dimensionnée à partir du besoin réel du prototype (et non sur estimation forfaitaire).

## Spécifications

| Paramètre | Valeur |
|---|---|
| Production (panneau) | Monocristallin 50 W (peak) |
| Stockage (batterie) | Plomb-acide 12 V / 20 Ah (240 Wh) |
| Bilan de puissance crête | 37,85 W (toutes charges ON) |
| Consommation journalière estimée | ≈ 113,5 Wh (pour 3 h de travail) |
| Autonomie théorique (sans soleil) | ≈ 1 jour (à 50 % de décharge) |
| Conversion | Régulateurs Buck LM2596 (efficacité > 85 %) |

## Méthode de dimensionnement

**Étape 1 — Bilan de puissance crête.** Somme des consommations réelles des composants du prototype (deux moteurs, deux résistances, deux ventilateurs, ESP32) :

```
P_tot = 9,0 W (2 moteurs) + 24,0 W (2 résistances) + 3,6 W (2 ventilateurs) + 1,25 W (ESP32)
      = 37,85 W
```

**Étape 2 — Énergie consommée par jour.** Pour une utilisation de 3 h/jour (≈ 18 cycles de traitement) :

```
E_jour = 37,85 W × 3 h ≈ 113,5 Wh/jour
```

**Étape 3 — Validation de la batterie.** La batterie 12 V/20 Ah a une capacité totale de 240 Wh. En limitant la décharge à 50 % (standard pour prolonger la durée de vie d'une batterie au plomb), l'énergie réellement disponible est de **120 Wh**.

> 120 Wh disponibles > 113,5 Wh nécessaires → la batterie couvre une session de travail quotidienne en autonomie.

**Étape 4 — Validation du panneau solaire.** Avec un ensoleillement moyen de 5 h/jour au Bénin, le panneau de 50 W produit :

```
E_produite = 50 W × 5 h = 250 Wh/jour
```

> 250 Wh produits > 113,5 Wh nécessaires → le panneau recharge la batterie facilement, avec une marge de sécurité pour les jours de faible ensoleillement.

## Résultats mesurés en test

Voir [07-testing-validation.md](07-testing-validation.md#validation-du-système-énergétique) pour le profil de consommation mesuré au multimètre (pic maximum observé : 1,5 A, tension batterie stable > 12 V, aucun effondrement de tension constaté).

## Limites connues

L'autonomie réelle en cycle complet et la stabilité thermique de l'électronique sous fonctionnement prolongé n'ont pas encore été validées en conditions de terrain — voir [09-future-improvements.md](09-future-improvements.md).

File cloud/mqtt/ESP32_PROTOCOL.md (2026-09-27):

# Smart-Soja Platform — ESP32 Protocol Documentation

## Overview
The Smart-Soja platform communicates with ESP32 devices via **MQTT** over a hybrid bridge. This document specifies the exact message formats, topics, and data structures expected by the platform.

---

## MQTT Connection Parameters

```
Broker: wss://broker.hivemq.com:8884/mqtt (WebSocket Secure)
Protocol: MQTT 3.1.1
QoS: 1 (At Least Once)
```

---

## Topic Structure

### Base Topic Format
```
smart-soja/{category}/{unit-id}
```

### Available Topics

#### 1. **Telemetry (ESP32 → Platform)**
```
smart-soja/telemetry/{unit-id}
```
**Direction:** ESP32 publishes sensor & control state data  
**Frequency:** Every 2-5 seconds (recommended)  
**Payload:** JSON object

---

#### 2. **Lot Completion (ESP32 → Platform)**
```
smart-soja/lot_completed/{unit-id}
```
**Direction:** ESP32 publishes when processing cycle completes  
**Frequency:** On event  
**Payload:** JSON object with lot metadata

---

#### 3. **Commands (Platform → ESP32)**
```
smart-soja/commands/{unit-id}
```
**Direction:** Platform sends control commands  
**Frequency:** On user action or mode change  
**Payload:** JSON object

---

## Message Formats

### 1. Telemetry Payload

**Topic:** `smart-soja/telemetry/{unit-id}`

```json
{
  "unitId": "unit-001",
  "timestamp": 1716633600000,
  "humidity": 45.2,
  "temperature": 32.5,
  "weight": 42.8,
  "ir1": true,
  "ir2": false,
  "mode": "auto",
  "step": 3,
  "alarm": false,
  "controls": {
    "alimentation": false,
    "tamis": true,
    "ventilateur": false,
    "chauffage": true,
    "vis_soja": true,
    "servo_vanne": false
  },
  "battery": 95
}
```

**Field Descriptions:**

| Field | Type | Range | Description |
|---|---|---|---|
| `unitId` | String | - | Unique device identifier (e.g., "unit-001") |
| `timestamp` | Number | Unix ms | Current milliseconds since epoch |
| `humidity` | Number | 0-100 | Relative humidity in % |
| `temperature` | Number | -40 to 125 | Temperature in °C |
| `weight` | Number | 0-60000 | Weight in grams (or kg if > 200) |
| `ir1` | Boolean | true/false | IR1 sensor state (Soja en entrée) |
| `ir2` | Boolean | true/false | IR2 sensor state (Sac en Sortie) |
| `mode` | String | "auto" \| "manual" | Current operating mode |
| `step` | Number | 0-12 | Current GRAFCET step (0 = idle) |
| `alarm` | Boolean | true/false | Emergency alarm triggered? |
| `controls` | Object | - | State of all actuators (see below) |
| `controls.alimentation` | Boolean | true/false | Servo 1 (Trémie) state |
| `controls.tamis` | Boolean | true/false | Tamis motor state |
| `controls.ventilateur` | Boolean | true/false | Ventilateur motor state |
| `controls.chauffage` | Boolean | true/false | Chauffage heater state |
| `controls.vis_soja` | Boolean | true/false | Vis motor state |
| `controls.servo_vanne` | Boolean | true/false | Servo 2 (Vanne) state |
| `battery` | Number | 0-100 | Battery percentage (if applicable) |

---

### 2. Lot Completion Payload

**Topic:** `smart-soja/lot_completed/{unit-id}`

```json
{
  "unitId": "unit-001",
  "timestamp": 1716633600000,
  "lotId": "lot-20250525-001",
  "duration_ms": 180000,
  "weight_processed": 45200,
  "humidity_avg": 42.5,
  "temperature_avg": 31.8,
  "steps_completed": 12,
  "quality_score": 95
}
```

**Field Descriptions:**

| Field | Type | Description |
|---|---|---|
| `unitId` | String | Device identifier |
| `timestamp` | Number | When processing completed (Unix ms) |
| `lotId` | String | Unique lot identifier (auto-generated or provided) |
| `duration_ms` | Number | Total processing time in milliseconds |
| `weight_processed` | Number | Final weight in grams |
| `humidity_avg` | Number | Average humidity during processing |
| `temperature_avg` | Number | Average temperature during processing |
| `steps_completed` | Number | Total GRAFCET steps executed |
| `quality_score` | Number | 0-100 quality rating |

---

### 3. Command Payload (Platform → ESP32)

**Topic:** `smart-soja/commands/{unit-id}`

#### 3a. Mode Switch Command

```json
{
  "mode": "auto"
}
```

OR

```json
{
  "mode": "manual"
}
```

**Expected Response:** ESP32 publishes telemetry with updated `mode` field

---

#### 3b. Auto Mode Start Command

```json
{
  "mode": "auto",
  "action": "cycle_start"
}
```

**Expected Behavior:**
- ESP32 starts GRAFCET cycle (step 0 → step 1)
- Platform receives telemetry with `step > 0`
- Cycle progresses automatically

---

#### 3c. Manual Control Command

```json
{
  "action": "control_manual",
  "device": "servo_tremie",
  "state": "ON",
  "timestamp": 1716633600000
}
```

OR

```json
{
  "action": "control_manual",
  "device": "tamis",
  "state": "OFF",
  "timestamp": 1716633600000
}
```

**Valid Devices:**
- `servo_tremie` → Servo 1 (Alimentation/Trémie)
- `tamis` → Tamis motor
- `ventilateur` → Ventilateur motor
- `chauffage` → Chauffage heater
- `vis_soja` → Vis motor
- `servo_vanne` → Servo 2 (Vanne/Transfert)

**Valid States:**
- `"ON"` → Activate actuator
- `"OFF"` → Deactivate actuator

**Expected Response:** ESP32 toggles actuator and publishes telemetry confirming state change

---

#### 3d. Emergency Stop Command

```json
{
  "action": "emergency_stop",
  "timestamp": 1716633600000
}
```

**Expected Behavior:**
- ESP32 immediately cuts power to all actuators
- Sets `alarm: true` in telemetry
- Switches mode to `"manual"`
- Requires manual reset from platform

---

#### 3e. Test LED Command (Diagnostics)

```json
{
  "test_led": true
}
```

**Expected Behavior:** ESP32 blinks diagnostic LED to confirm connectivity

---

## MQTT Subscribe Topics (Platform Side)

The platform subscribes to these topics:

```
smart-soja/telemetry/+
smart-soja/lot_completed/+
```

The `+` wildcard matches any `unit-id`.

---

## Example Flow: MANUAL Mode Control

### Scenario: User clicks "Alimentation ON" button

**1. Platform publishes command:**
```
Topic: smart-soja/commands/unit-001
Payload: {
  "action": "control_manual",
  "device": "servo_tremie",
  "state": "ON",
  "timestamp": 1716633605000
}
```

**2. ESP32 receives & executes:**
- Activates Servo 1 (Trémie) pin
- Sets internal state: `controls.alimentation = true`

**3. ESP32 publishes telemetry:**
```
Topic: smart-soja/telemetry/unit-001
Payload: {
  "unitId": "unit-001",
  "timestamp": 1716633605500,
  "humidity": 45.2,
  "temperature": 32.5,
  "weight": 42.8,
  "ir1": true,
  "ir2": false,
  "mode": "manual",
  "step": 0,
  "alarm": false,
  "controls": {
    "alimentation": true,      ← UPDATED
    "tamis": false,
    "ventilateur": false,
    "chauffage": false,
    "vis_soja": false,
    "servo_vanne": false
  },
  "battery": 95
}
```

**4. Platform receives & updates UI:**
- Control card "Alimentation" gets `.active` class
- Status text changes to "ACTIF"
- Icon animates with pulsing effect

---

## Example Flow: AUTO Mode Cycle

### Scenario: User clicks "Automatique" button

**1. Platform publishes:**
```
Topic: smart-soja/commands/unit-001
Payload: {
  "mode": "auto",
  "action": "cycle_start"
}
```

**2. ESP32 enters AUTO mode:**
- Starts GRAFCET state machine
- Automatically controls all actuators per program

**3. ESP32 publishes periodic telemetry:**
```
Topic: smart-soja/telemetry/unit-001
Payload: {
  "unitId": "unit-001",
  "timestamp": 1716633606000,
  "humidity": 45.5,
  "temperature": 32.7,
  "weight": 42.9,
  "ir1": true,
  "ir2": false,
  "mode": "auto",
  "step": 2,              ← PROGRESSING
  "alarm": false,
  "controls": {
    "alimentation": true,  ← MANAGED BY ESP32
    "tamis": true,
    "ventilateur": false,
    "chauffage": true,
    "vis_soja": true,
    "servo_vanne": false
  },
  "battery": 95
}
```

**4. When cycle completes:**
```
Topic: smart-soja/lot_completed/unit-001
Payload: {
  "unitId": "unit-001",
  "timestamp": 1716633780000,
  "lotId": "lot-20250525-001",
  "duration_ms": 180000,
  "weight_processed": 45200,
  "humidity_avg": 42.5,
  "temperature_avg": 31.8,
  "steps_completed": 12,
  "quality_score": 95
}
```

**5. Platform:**
- Receives completion event
- Creates Lot record in Firestore
- Resets UI to idle state

---

## Error Handling

### ESP32 Connection Lost
- Platform sets `isConnected: false`
- MQTT badge turns red
- All control buttons disabled
- Shows "DÉCONNECTÉ" status

### ESP32 Sends Invalid JSON
- Platform logs error to console
- Ignores malformed message
- Remains in previous state

### Telemetry Timeout (>15s no data)
- Platform switches data source badge to "SIMU"
- Uses simulated/cached data
- Shows warning (optional)

### Emergency Alarm Received
- Platform calls `emergencyStop()`
- All controls disabled
- Shows red emergency banner
- Requires manual reset

---

## Debug/Diagnostics Commands

### Query Device Status
```json
{
  "action": "ping"
}
```
**Expected Response:** Telemetry message with `step: 0`

### Force Reset
```json
{
  "action": "reset"
}
```
**Expected Behavior:** ESP32 reinitializes all systems and publishes telemetry

### Request Full State Dump
```json
{
  "action": "dump_state"
}
```
**Expected Response:** Complete JSON of all internal ESP32 state variables

---

## Constraints & Limits

| Parameter | Limit | Note |
|---|---|---|
| Message Size | < 1024 bytes | MQTT payload limit |
| Telemetry Frequency | 2-5s | Avoid >1s (bandwidth) |
| Timeout | 15s | Platform assumes disconnected |
| Max Weight | 60000g | Clamp or error if exceeded |
| Max Humidity | 100% | Clamp or error if exceeded |
| Max Temperature | 125°C | Sensor max; clamp if higher |

---

## Firmware Integration Checklist

- [ ] MQTT client connects to `wss://broker.hivemq.com:8884/mqtt`
- [ ] Subscribes to `smart-soja/commands/{unitId}`
- [ ] Publishes telemetry every 3-5 seconds
- [ ] Implements all 6 actuator control signals
- [ ] Reads all 4 sensor inputs (humidity, temp, weight, IR1, IR2)
- [ ] Implements GRAFCET state machine (steps 0-12)
- [ ] Handles mode switching (AUTO ↔ MANUAL)
- [ ] Publishes `lot_completed` events on cycle end
- [ ] Implements emergency stop signal
- [ ] Validates incoming JSON commands
- [ ] Retries on connection loss
- [ ] Maintains time synchronization via timestamp fields

---

## Testing Checklist (Platform)

- [ ] Receives telemetry updates every 3-5 seconds
- [ ] Control cards toggle correctly in MANUAL mode
- [ ] Controls disabled (opacity 0.5) in AUTO mode
- [ ] Mode toggle switches work (AUTO ↔ MANUAL)
- [ ] Emergency stop cuts all actuators
- [ ] Lot completion creates records in Firestore
- [ ] Telemetry data persists across page reloads
- [ ] No console errors or MQTT errors
- [ ] UI responsive to real sensor data
- [ ] MQTT badge shows connected/disconnected

---

## Support & Debugging

If ESP32 doesn't communicate:

1. **Check MQTT Broker Connectivity:**
   - Test with MQTT client tool (MQTT Explorer, MQTTbox)
   - Verify WiFi connection on ESP32

2. **Verify Topics:**
   - Confirm topic names match exactly (case-sensitive)
   - Ensure `unitId` is consistent across all messages

3. **Check Payload Format:**
   - Validate JSON syntax (use online validator)
   - Ensure all required fields present

4. **Enable Debug Logs:**
   - Platform: Open browser DevTools → Console
   - ESP32: Enable serial debug output

5. **Test with Manual Commands:**
   ```
   Platform → smart-soja/commands/unit-001
   {"mode": "manual"}
   ```
   Expect ESP32 telemetry response within 2 seconds

---

**Last Updated:** May 25, 2026  
**Platform Version:** Smart-Soja v2.0  
**Status:** Production Ready ✅

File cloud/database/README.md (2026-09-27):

# Database (Firebase)

SMART-SOJA utilise **Firebase Firestore** comme base de données temps réel pour la traçabilité. La configuration de déploiement (règles de sécurité, index, jeu de données initial) vit avec l'application qui la déploie : [`cloud/dashboard/app/firestore.rules`](../dashboard/app/firestore.rules), [`firestore.indexes.json`](../dashboard/app/firestore.indexes.json), [`rtdb_seed.json`](../dashboard/app/rtdb_seed.json).

## Collections principales

| Collection | Contenu |
|---|---|
| `users` | Comptes utilisateurs et rôles (admin / industrie / exploitant) |
| `units` | Unités SMART-SOJA déployées (flotte), identifiées par `unitId` |
| `lots` | Lots de soja traités : passeport numérique (voir format JSON dans [05-software-architecture.md](../../docs/05-software-architecture.md)) |
| `telemetry` | Historique des trames de télémétrie périodique publiées via MQTT |

## Règles d'accès

Accès en lecture/écriture réservé aux utilisateurs authentifiés (`request.auth != null`), avec une règle plus fine sur `users/{userId}` : un utilisateur peut lire/modifier son propre profil, ou tout profil s'il a le rôle `admin`.

## Flux d'alimentation

Le pipeline MQTT → Firestore est assuré par [`cloud/api/`](../api/) (backend Node.js), qui valide chaque message avant écriture. Voir [02-system-architecture.md](../../docs/02-system-architecture.md) pour le schéma complet.

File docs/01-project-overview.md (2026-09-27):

# Project Overview

SMART-SOJA

## Contexte

Le soja (*Glycine max*) occupe une place croissante dans l'économie agricole du Bénin : la production nationale est passée de 157 620 tonnes en 2015 à plus de 257 000 tonnes en 2020, faisant du soja la 4ᵉ source de devises du pays. L'émergence de la **Zone Industrielle de Glo-Djigbé (GDIZ)** impose désormais des standards de qualité stricts aux lots livrés par les producteurs, encadrés par la norme béninoise **NB 01.07.004** (homologuée en 2021) :

- Taux d'humidité **< 12 %** (seuil critique contre les moisissures et pour la performance des presses à huile)
- Pureté spécifique **> 98 %** (absence de débris végétaux, cailloux, grains brisés)
- Intégrité du grain (limitation des grains cassés)

Or, le battage traditionnel et le séchage au sol pratiqués en zone rurale ne permettent pas d'atteindre ces standards : le diagnostic du MAEP et de l'UNPS relève des **pertes post-récolte de 15 à 25 %** et des refoulements réguliers de camions aux portes des usines.

## Problématique

> Comment concevoir une unité mobile et autonome de pré-traitement du soja permettant d'améliorer le nettoyage, le contrôle de l'humidité, la pesée et la traçabilité des lots dans les zones rurales de production au Bénin ?

## Objectifs

**Objectif général** — Concevoir une unité mobile, autonome et connectée de pré-traitement du soja adaptée au nettoyage, au séchage, à la pesée et à la traçabilité numérique des lots en milieu rural béninois.

**Objectifs spécifiques**
1. **Analyser** les besoins de pré-traitement du soja et les exigences de qualité des unités de transformation.
2. **Développer** une solution mécatronique intégrant les sous-systèmes mécanique, électronique, énergétique et logiciel.
3. **Évaluer** les performances fonctionnelles du prototype (nettoyage, humidité, pesée, consommation énergétique, traçabilité).

## Solution proposée

SMART-SOJA est une unité mobile qui combine :

| Sous-système | Rôle |
|---|---|
| Mécanique | Nettoyage par tamisage vibrant, séchage actif par air chaud brassé, pesée |
| Électronique | Acquisition capteurs (humidité, température, présence, poids) et pilotage des actionneurs 12 V |
| Contrôle-commande | ESP32 + FreeRTOS, logique séquentielle GRAFCET, sécurité prioritaire |
| Énergie | Panneau solaire 50 W + batterie plomb-acide 12 V/20 Ah, autonomie hors réseau |
| IoT & traçabilité | MQTT + JSON, tableau de bord web, génération d'un passeport numérique par lot (QR Code) |

Comparée au tri manuel (peu ou pas de mesure instrumentée ni de traçabilité numérique) et aux unités industrielles plus lourdes, SMART-SOJA cherche à rapprocher les fonctions de pré-traitement du producteur : architecture énergétique hors réseau, double mesure capacitive de l'humidité et traçabilité numérique des lots.

## Origine du projet

Le projet a été co-développé par **Elisa Christelle LOKO** et **Dodji Virgile TCHIDEHOU** dans le cadre de leur projet de fin de cycle (Licence Professionnelle en Informatique Industrielle et Maintenance, EGEI/UCAO-UUC), sous la supervision du **Dr DIDAVI Audace**. Le travail a été mené dans le contexte du stage académique chez **QOTTO Bénin**, dont l'environnement technique a nourri plusieurs choix de conception liés à l'énergie, aux systèmes embarqués et à la maintenance électronique.

## État d'avancement (juin 2026)

Le prototype est un **démonstrateur fonctionnel validé principalement par tests unitaires et intégration partielle** : les principaux sous-systèmes (capteurs, moteurs, séchage, transmission MQTT, génération de QR Code) ont été vérifiés individuellement. Lors des essais MQTT documentés en laboratoire, aucune perte de message ni payload invalide n'a été observé. Restent à valider avant tout déploiement : le cycle complet nettoyage + séchage en charge réelle (2 à 5 kg), l'intégration finale du module de pesée (HX711), l'autonomie sur cycle complet et la robustesse en conditions de terrain. Voir [08-results.md](08-results.md) pour le détail des résultats et [09-future-improvements.md](09-future-improvements.md) pour la feuille de route.

## Pour aller plus loin

- [02-system-architecture.md](02-system-architecture.md) — architecture globale Edge/Cloud/Application
- [03-hardware-design.md](03-hardware-design.md) — électronique et PCB
- [04-mechanical-design.md](04-mechanical-design.md) — conception mécanique
- [05-software-architecture.md](05-software-architecture.md) — firmware FreeRTOS, GRAFCET, plateforme web
- [06-energy-system.md](06-energy-system.md) — dimensionnement solaire/batterie
- [research/thesis/](../research/thesis/) — figures et éléments de travail issus du mémoire ; le PDF complet n'est pas distribué dans le dépôt public

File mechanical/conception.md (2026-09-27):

# Documentation Technique : Conception Mécanique SMART-SOJA

Ce document détaille la conception mécanique du système **SMART-SOJA**, réalisée sous logiciel de CAO professionnel (**SolidWorks**). L'architecture est basée sur une approche modulaire permettant une maintenance aisée et une fabrication par sous-ensembles.

---

## 1. Architecture Modulaire Globale

Le système est structuré en un châssis porteur accueillant quatre blocs fonctionnels amovibles. Cette conception garantit la polyvalence du système et facilite le transport en milieu agricole.

```mermaid
graph TD
    CH[Châssis Mobile] --> B1[Bloc 1 : Alimentation]
    CH --> B2[Bloc 2 : Nettoyage/Tamisage]
    CH --> B3[Bloc 3 : Séchage/Brassage/Analyse]
    CH --> B4[Bloc 4 : Pesée/Réception]
```

---

## 2. Unité Structurelle : Le Châssis

Le châssis constitue le squelette du système. Il a été conçu pour allier robustesse et mobilité.

* **Composants Clés** :
  * **Structure principale** : Châssis mécano-soudé ou profilé.
  * **Mobilité** : Système de 4 roues avec axes renforcés pour les terrains irréguliers.
  * **Accessibilité** : Utilisation de charnières et d'une porte pour l'accès technique à la partie électronique.

---

## 3. Analyse des Blocs Fonctionnels

### 3.1 Bloc 1 : Unité d'Entrée (Alimentation)

Situé en haut de la machine, ce bloc gère l'arrivée du soja brut.

* **Organe principal** : Trémie d'entrée.
* **Fonctionnement** : Écoulement gravitaire assisté par un servomoteur.

### 3.2 Bloc 2 : Unité de Nettoyage et Vibration

Ce bloc assure le retrait des impuretés (cailloux, poussières).

* **Tamisage** : Système de deux tamis superposés  avec des mailles de différentes tailles.
* **Vibration** : Utilisation d'un moteur à courant continu **JGA25-370** monté sur un support dédié.
* **Transmission** : Système de poulie et tige de transmission pour transformer le mouvement de rotation en oscillation vibratoire du tamis.

### 3.3 Bloc 3 : Unité de Séchage et Analyse (Cœur du Système)

C'est le bloc le plus complexe, assurant la régulation de l'humidité.

* **Brassage** : Une **vis sans fin** de type Archimède  assure le mouvement et le brassae constant du soja pour un séchage homogène.
* **Séchage** : Intégration d'un ensemble **Ventilateur + Résistance Chauffante (RC)**.
* **Analyse IoT** : Boîtiers spécifiques pour les capteurs d'humidité capacitifs, températures et support pour capteur infrarouge.

### 3.4 Bloc 4 : Unité de Pesée et Réception

Dernière étape du processus avant la mise en sac.

* **Mesure** : Support pour cellule de charge (**Load Cell**) permettant une pesée en temps réel du soja traité.
* **Réception** : Plateau support et bocal de réception finale.

---

## 4. Spécifications de Fabrication

* **Logiciel de CAO** : SolidWorks.
* **Matériaux envisagés** :
  * Acier galvanisé ou aluminium pour le châssis.
  * Plastique alimentaire (type PETG/PLA) pour quelques pièces d'assemblages et boîtiers capteurs (impression 3D).
  * Contre plaquet pour les parois de la zone de séchage.
* **Maintenance** : Chaque bloc peut être retiré du châssis sans démonter l'intégralité du système.

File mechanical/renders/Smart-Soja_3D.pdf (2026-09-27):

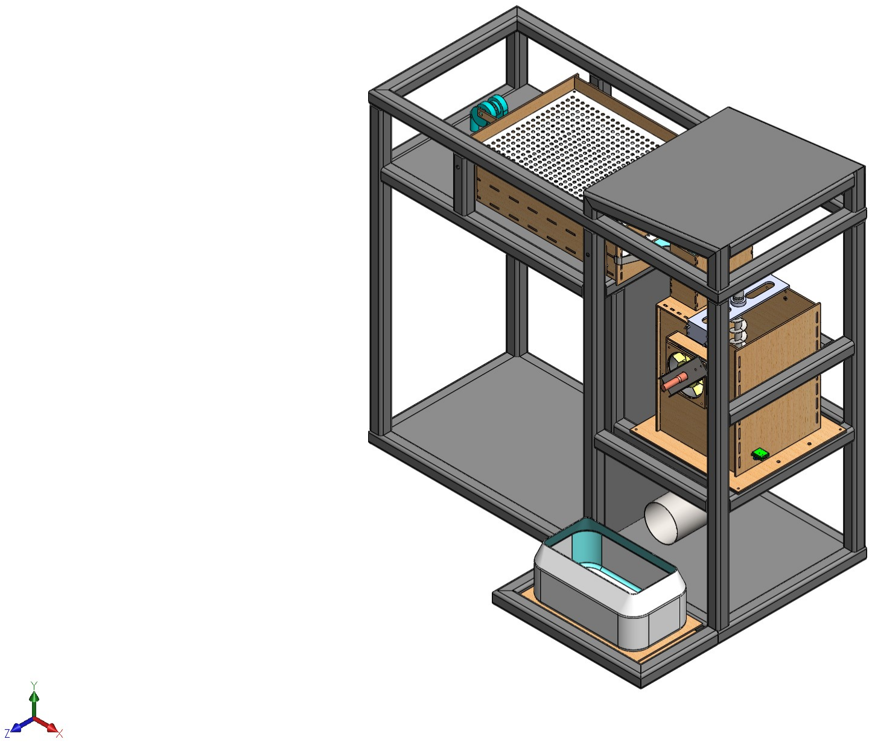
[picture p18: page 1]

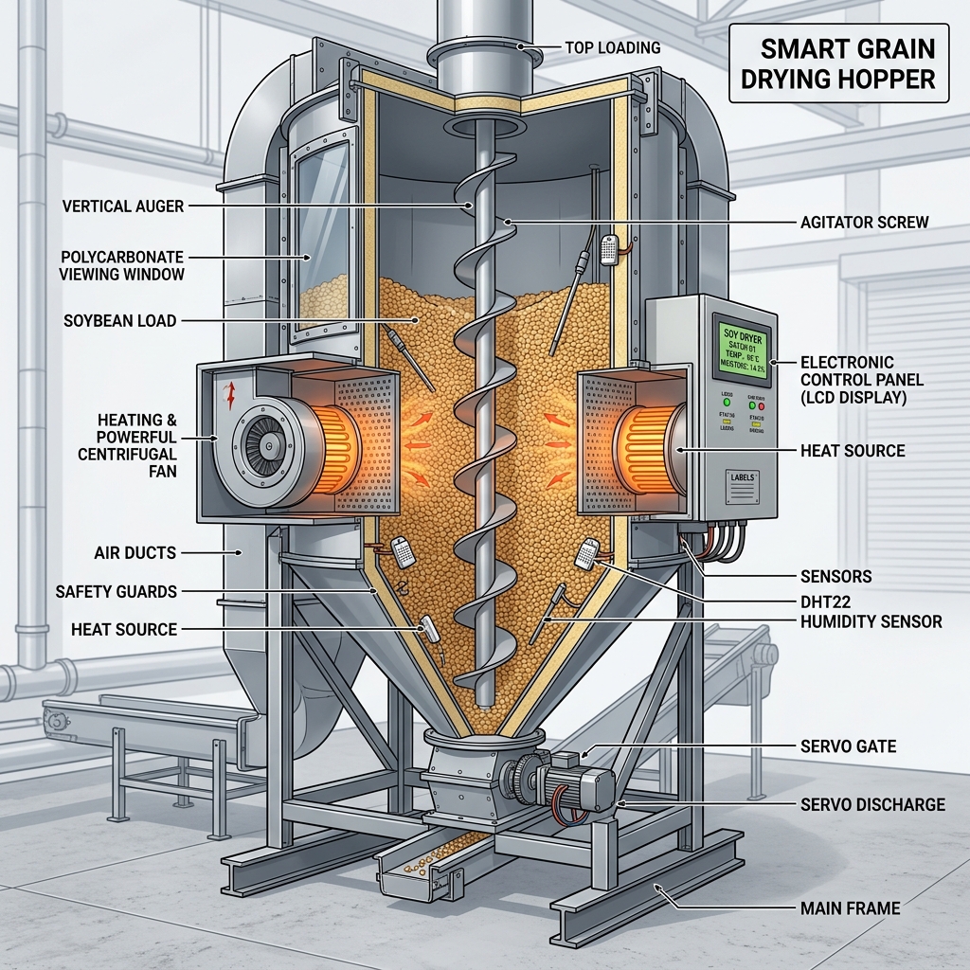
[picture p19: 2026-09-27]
media/diagrams/concept_sechage_smart.png

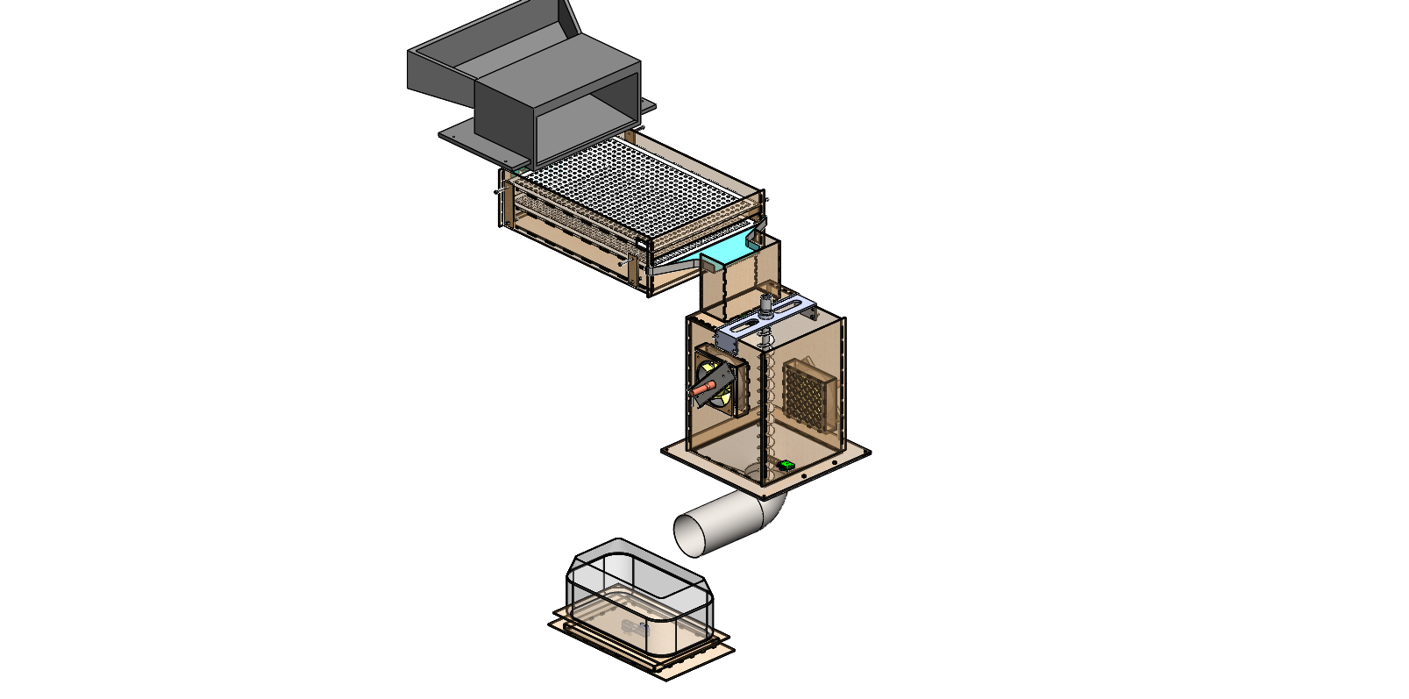
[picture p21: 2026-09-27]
mechanical/renders/decomposition_3D.PNG

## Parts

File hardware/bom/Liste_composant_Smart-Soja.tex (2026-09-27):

\documentclass[11pt,a4paper]{article}

%================= PACKAGES =================
\usepackage[utf8]{inputenc}
\usepackage[T1]{fontenc}
\usepackage[french]{babel}
\usepackage{geometry}
\usepackage{array}
\usepackage[table]{xcolor}
\usepackage{booktabs}
\usepackage{tabularx}
\usepackage{titlesec}

\geometry{margin=1.5cm}

%================= STYLE =================
\titleformat{\section}
{\large\bfseries}
{}
{0em}
{}

\renewcommand{\arraystretch}{1.2}

%================= DOCUMENT =================
\begin{document}

\begin{center}
    {\LARGE \textbf{SMART-SOJA}}\\[5pt]
    {\large Liste de Matériel (BOM)}\\[3pt]
    \textit{Document destiné à l'achat des composants électroniques}
\end{center}

\vspace{8pt}

\begin{tabularx}{\textwidth}{>{\centering\arraybackslash}p{1.5cm} | X | X | >{\centering\arraybackslash}p{3cm}}
\toprule
\rowcolor{gray!30}
\textbf{Qté} & \textbf{Désignation} & \textbf{Référence / Footprint} & \textbf{Catégorie} \\
\midrule

1 & ESP32-DEVKITC-32E & MODULE\_ESP32-DEVKITC-32E & Microcontrôleur \\
\rowcolor{gray!10}
1 & Écran LCD 16x2 avec interface I2C & LCD16X2\_I2C (DS1) & Affichage \\
1 & Capteur DHT22 (Température \& Humidité) & DHT22 (U1) & Capteur \\
\rowcolor{gray!10}
2 & Capteur Infrarouge (IR) & IR1, IR2 & Capteur \\
2 & Sonde d'humidité du sol & Soil1, Soil2 & Capteur \\
\rowcolor{gray!10}
1 & Module Amplificateur HX711 & Module HX711 (J8) & Module \\
1 & Module Lecteur Carte SD & SD Card (J12) & Module \\
\rowcolor{gray!10}
1 & Module Régulateur Buck LM2596 & LM2596 (J5) & Alimentation \\

2 & Moteur DC 12V (JGA25-370) & Motor1, Motor2 & Actionneur \\
\rowcolor{gray!10}
1 & Servomoteur SG90 & Motor\_Servo (M1) & Actionneur \\
1 & Ventilateur 12V DC & FAN\_12V (J13) & Actionneur \\
\rowcolor{gray!10}
1 & Résistance chauffante 12V & HEATER\_12V (J11) & Actionneur \\
1 & Buzzer 12V & BZ1 & Alerte \\

\rowcolor{gray!10}
1 & Fusible 5A & F1 & Protection \\
1 & Prise Jack Alim 12V & BarrelJack\_Horizontal (J1) & Connectique \\
\rowcolor{gray!10}
2 & Bouton poussoir 6mm & SW1, SW2 & Interface \\

4 & MOSFET de puissance & IRLZ44N (Q1-Q4) & Actif \\
\rowcolor{gray!10}
1 & Transistor NPN & BC547 (Q5) & Actif \\
6 & Diode de puissance & 1N5408 & Actif \\
\rowcolor{gray!10}
5 & LED (Rouge/Vert/Bleu) & D2, D3, D6-D8 & Actif \\

7 & Résistance 10k$\Omega$ & R2, R6, R7, R12, R13, R15, R16 & Passif \\
\rowcolor{gray!10}
4 & Résistance 4.7k$\Omega$ & R8, R9, R17, R18 & Passif \\
2 & Résistance 1k$\Omega$ & R1, R3 & Passif \\
\rowcolor{gray!10}
6 & Résistance 220$\Omega$ & R4, R5, R10, R11, R14, R19 & Passif \\

10 & Condensateur 100nF & C1, C3, C4, C6, C7, C9, C10, C13, C18, C19 & Passif \\
\rowcolor{gray!10}
6 & Condensateur 470µF & C5, C8, C14, C15, C20, C21 & Passif \\
4 & Condensateur 10µF & C11, C12, C16, C17 & Passif \\
\rowcolor{gray!10}
1 & Condensateur 100µF & C2 & Passif \\

6 & Bornier à vis 2 contacts & J3, J9, J10, J11, J13, J14 & Connectique \\
\rowcolor{gray!10}
2 & Barrette de pins mâles (40 broches à découper) & Strip Header Male & Connectique \\
2 & Barrette de pins femelles (40 broches à découper) & Strip Header Female & Connectique \\

\bottomrule
\end{tabularx}

\vspace{10pt}

\begin{center}
\textit{Document généré pour approvisionnement des composants du projet SMART-SOJA}
\end{center}

\end{document}

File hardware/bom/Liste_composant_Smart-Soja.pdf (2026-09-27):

## SMART-SOJA

Liste de Matériel (BOM)

Document destiné à l’achat des composants électroniques

Qté | Désignation | Référence / Footprint | Catégorie
1 | ESP32-DEVKITC-32E | MODULE_ESP32-DEVKITC-32E | Microcontrôleur
1 | Écran LCD 16x2 avec interface I2C | LCD16X2_I2C (DS1) | Affichage
1 | Capteur DHT22 (Température & Humidité) | DHT22 (U1) | Capteur
2 | Capteur Infrarouge (IR) | IR1, IR2 | Capteur
2 | Sonde d’humidité du sol | Soil1, Soil2 | Capteur
1 | Module Amplificateur HX711 | Module HX711 (J8) | Module
1 | Module Lecteur Carte SD | SD Card (J12) | Module
1 | Module Régulateur Buck LM2596 | LM2596 (J5) | Alimentation
2 | Moteur DC 12V (JGA25-370) | Motor1, Motor2 | Actionneur
1 | Servomoteur SG90 | Motor_Servo (M1) | Actionneur
1 | Ventilateur 12V DC | FAN_12V (J13) | Actionneur
1 | Résistance chauffante 12V | HEATER_12V (J11) | Actionneur
1 | Buzzer 12V | BZ1 | Alerte
1 | Fusible 5A | F1 | Protection
1 | Prise Jack Alim 12V | BarrelJack_Horizontal (J1) | Connectique
2 | Bouton poussoir 6mm | SW1, SW2 | Interface
4 | MOSFET de puissance | IRLZ44N (Q1-Q4) | Actif
1 | Transistor NPN | BC547 (Q5) | Actif
6 | Diode de puissance | 1N5408 | Actif
5 | LED (Rouge/Vert/Bleu) | D2, D3, D6-D8 | Actif
7 | Résistance 10kΩ | R2, R6, R7, R12, R13, R15, R16 | Passif
4 | Résistance 4.7kΩ | R8, R9, R17, R18 | Passif
2 | Résistance 1kΩ | R1, R3 | Passif
6 | Résistance 220Ω | R4, R5, R10, R11, R14, R19 | Passif
10 | Condensateur 100nF | C1, C3, C4, C6, C7, C9, C10, C13, C18, C19 | Passif
6 | Condensateur 470µF | C5, C8, C14, C15, C20, C21 | Passif
4 | Condensateur 10µF | C11, C12, C16, C17 | Passif
1 | Condensateur 100µF | C2 | Passif
6 | Bornier à vis 2 contacts | J3, J9, J10, J11, J13, J14 | Connectique
2 | Barrette de pins mâles (40 broches à découper) | Strip Header Male | Connectique
2 | Barrette de pins femelles (40 broches à découper) | Strip Header Female | Connectique

Document généré pour approvisionnement des composants du projet SMART-SOJA

1

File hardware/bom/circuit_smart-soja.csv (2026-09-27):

Id | Référence | Empreinte | Quantité | Désignation | Fournisseur et réf
1 | C1,C4,C3,C6,C7,C9 | C_Disc_D14.5mm_W5.0mm_P10.00mm | 6 | 100nF
2 | C2 | C_Radial_D8.0mm_H11.5mm_P3.50mm | 1 | 100uF
3 | C5,C8 | C_Radial_D10.0mm_H12.5mm_P5.00mm | 2 | 470uF
4 | C15,C14,C20,C21 | C_Radial_D10.0mm_H12.5mm_P5.00mm | 4 | 470u
5 | C19,C10,C18,C13 | C_Disc_D14.5mm_W5.0mm_P10.00mm | 4 | 100n
6 | C12,C16,C17,C11 | C_Radial_D8.0mm_H11.5mm_P3.50mm | 4 | 10u
7 | Q4,Q2,Q1,Q3 | TO254P1054X469X1930-3 | 4 | IRLZ44N
8 | R3,R1 | R_Axial_DIN0414_L11.9mm_D4.5mm_P20.32mm_Horizontal | 2 | 1k
9 | R7,R15,R2,R6,R12,R13,R16 | R_Axial_DIN0414_L11.9mm_D4.5mm_P20.32mm_Horizontal | 7 | 10k
10 | R10,R4,R5,R11,R19,R14 | R_Axial_DIN0414_L11.9mm_D4.5mm_P20.32mm_Horizontal | 6 | 220
11 | Q5 | TO-92_Inline | 1 | BC547
12 | D11,D10,D9,D5,D4,D1 | D_DO-201AD_P15.24mm_Horizontal | 6 | 1N5408
13 | D3,D2,D8,D7,D6 | LED_D3.0mm | 5 | LED
14 | J1 | BarrelJack_Horizontal | 1 | J_IN_12V
15 | U2 | MODULE_ESP32-DEVKITC-32E | 1 | ESP32-DEVKITC-32E
16 | U1 | PinHeader_1x04_P2.54mm_Vertical | 1 | DHT22
17 | SW2 | SW_PUSH_6mm_H4.3mm | 1 | OFF
18 | SW1 | SW_PUSH_6mm_H4.3mm | 1 | ON
19 | R18,R17,R9,R8 | R_Axial_DIN0414_L11.9mm_D4.5mm_P20.32mm_Horizontal | 4 | 4.7k
20 | M1 | PinHeader_1x03_P2.54mm_Vertical | 1 | Motor_Servo
21 | J14 | T-Block-2 | 1 | Motor2 12V
22 | J13 | T-Block-2 | 1 | FAN_12V
23 | J12 | PinHeader_1x06_P2.54mm_Vertical | 1 | SD Card
24 | J11 | T-Block-2 | 1 | HEATER_12V
25 | J10 | T-Block-2 | 1 | Motor1 12V
26 | J9 | T-Block-2 | 1 | J_OUT_5V
27 | J8 | PinSocket_1x04_P1.27mm_Vertical | 1 | Module HX711
28 | J7 | PinSocket_1x03_P1.27mm_Vertical | 1 | IR2
29 | J6 | PinSocket_1x03_P1.27mm_Vertical | 1 | IR1
30 | J5 | PinHeader_1x02_P2.54mm_Vertical | 1 | LM2596
31 | J4 | PinSocket_1x03_P1.27mm_Vertical | 1 | Soil2
32 | J3 | T-Block-2 | 1 | J_OUT_12V
33 | J2 | PinSocket_1x03_P1.27mm_Vertical | 1 | Soil1
34 | F1 | Fuse_SunFuse-6HP | 1 | 5A
35 | DS1 | PinHeader_1x04_P2.54mm_Vertical | 1 | LCD16X2_I2C
36 | BZ1 | Buzzer_12x9.5RM7.6 | 1 | Buzzer

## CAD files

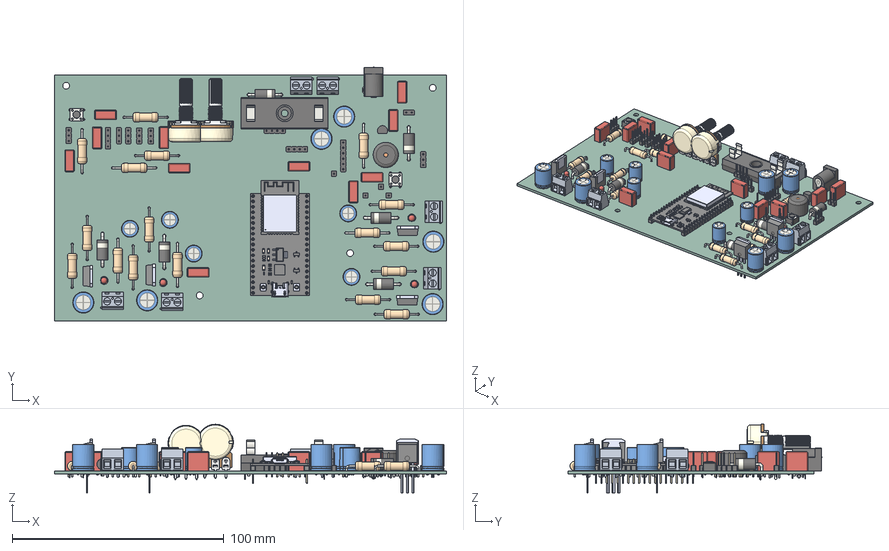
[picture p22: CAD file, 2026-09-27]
hardware/pcb/circuit_smart-soja/circuit_smart-soja.step
185.0 x 119.8 x 32.4 mm
C_Rect_L10.3mm_W4.5mm_P7.50mm_MKS4 x 11
D_DO-201AD_P15.24mm_Horizontal x 6
IRLZ44N x 4
T-Block-2 x 6
SW_PUSH_6mm_H4.3mm x 2
Pe柱^Potenciometro x 2
Pe柲^Potenciometro x 2
Pe柳^Potenciometro x 2
Pe柵^Potenciometro x 2
Pe柶^Potenciometro x 6
R_Axial_DIN0414_L11.9mm_D4.5mm_P20.32mm_Horizontal x 17
PinHeader_1x03_P2.54mm_Vertical x 6
C_Radial_D10.0mm_H12.5mm_P5.00mm x 6
PinHeader_1x01_P2.54mm_Vertical x 4
PinHeader_1x02_P2.54mm_Vertical
C_Radial_D8.0mm_H11.5mm_P3.50mm x 5
PinHeader_1x04_P2.54mm_Vertical x 3
TO-92_Inline
LED_D3.0mm x 4
Fuseholder_Cylinder-6.3x32mm_Schurter_0031-8002_Horizontal_Open
Buzzer_12x9.5RM7.6
board
header x 2
ESP32-WROOM-32D
micro usb
button x 2
CP2102N-A01-GQFN28
AMS1117-3.3
SS8050-G
components^DEVKIT V1 ESP32-WROOM-32
PinHeader_1x06_P2.54mm_Vertical
BarrelJack_Horizontal
circuit_smart-soja_PCB

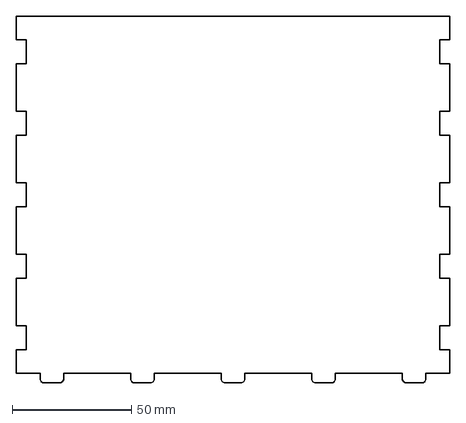
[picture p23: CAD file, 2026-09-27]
mechanical/drawings/Decoupe_Laser/sechage_face8.DXF
182.0 x 154.0 mm

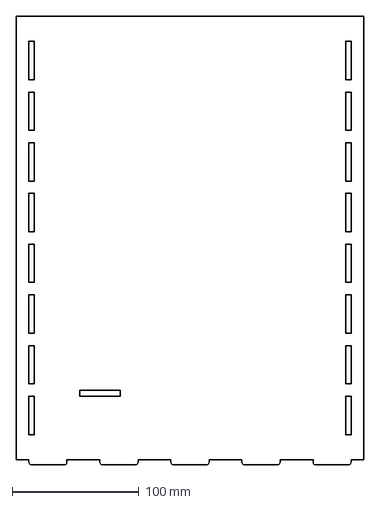
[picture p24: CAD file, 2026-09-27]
mechanical/drawings/sechageDDD1.DXF
274.0 x 354.0 mm

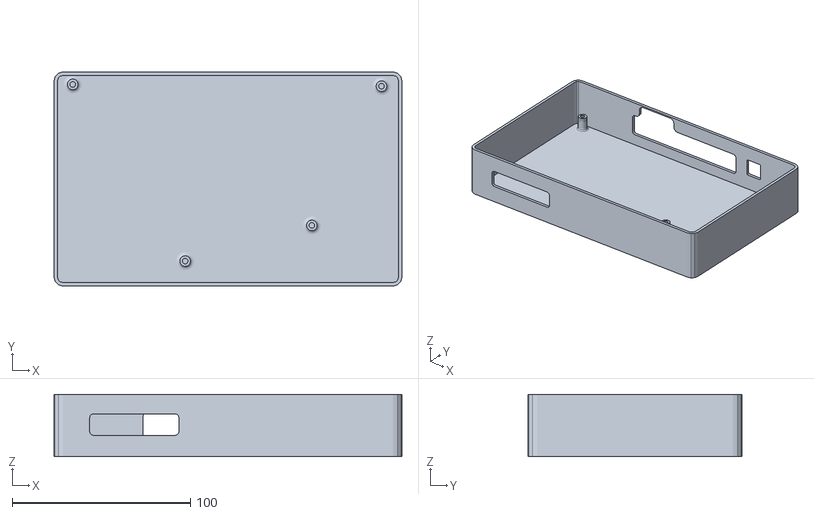
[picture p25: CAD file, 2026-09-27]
mechanical/stl/piece1_boitier_command.STL
195.0 x 120.0 x 35.0

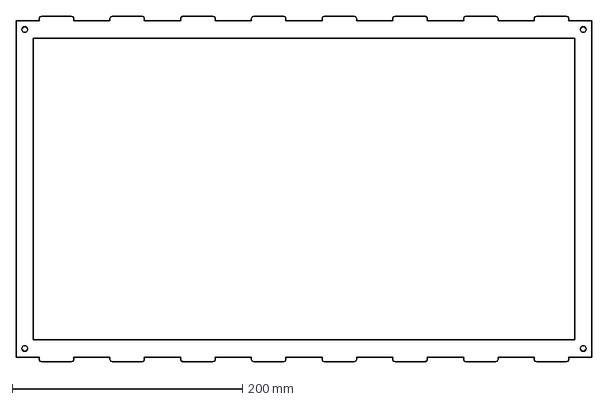
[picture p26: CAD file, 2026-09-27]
mechanical/drawings/Decoupe_Laser/support_tamis_f3.DXF
500.0 x 300.0 mm

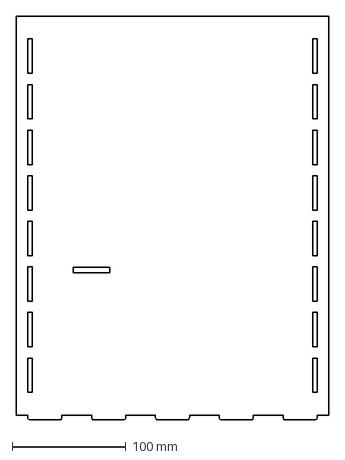
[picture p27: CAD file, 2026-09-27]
mechanical/drawings/sechageDDD2.DXF
274.0 x 354.0 mm

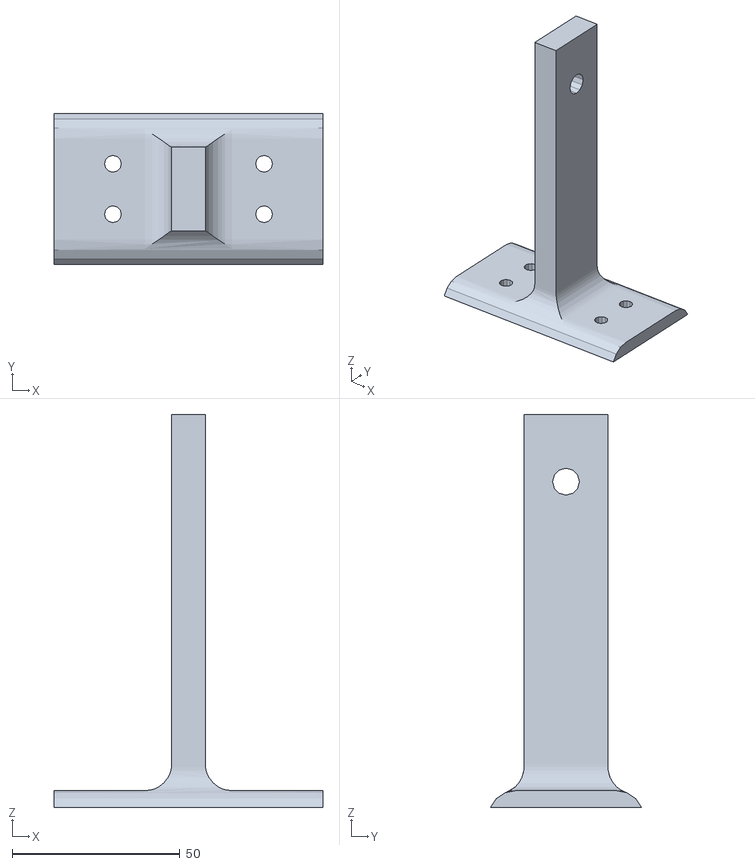
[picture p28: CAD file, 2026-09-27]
mechanical/stl/pièce_transmission.STL
80.0 x 45.0 x 117.0

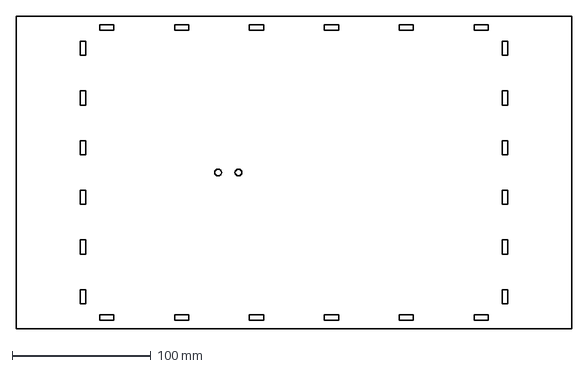
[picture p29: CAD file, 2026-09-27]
mechanical/drawings/Decoupe_Laser/Etat déplié1- plateau_support.DXF
400.0 x 225.0 mm

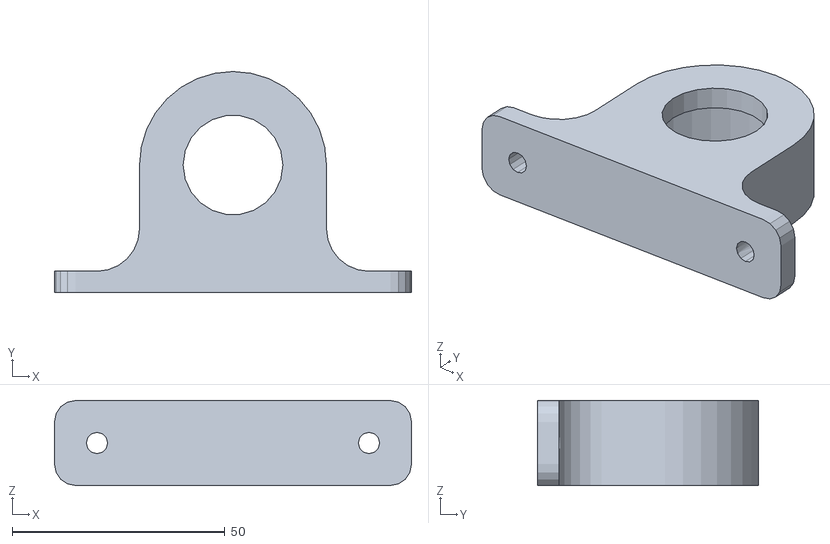
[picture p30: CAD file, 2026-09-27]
mechanical/stl/pallier_roulement.STL
84.0 x 52.0 x 20.0

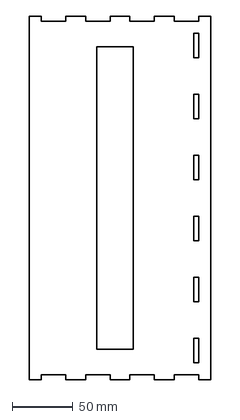
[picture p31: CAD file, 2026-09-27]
mechanical/drawings/Decoupe_Laser/support_tamis_f6.DXF
150.0 x 300.0 mm

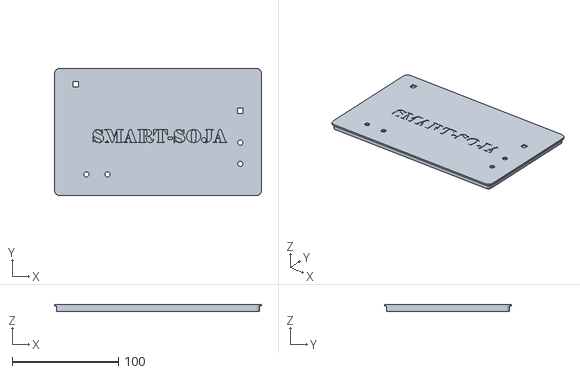
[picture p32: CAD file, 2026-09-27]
mechanical/stl/piece2_boitier_command.STL
195.0 x 120.0 x 6.50

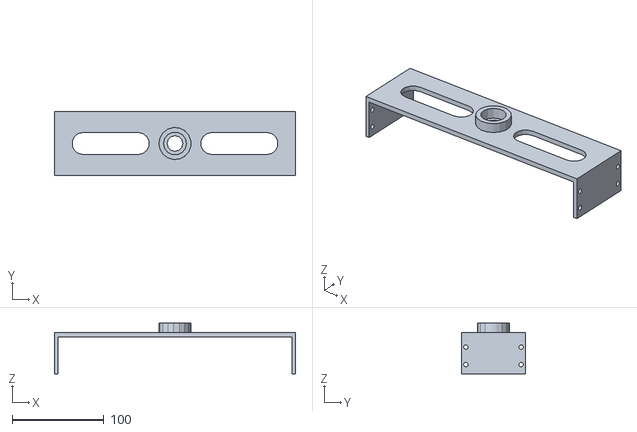
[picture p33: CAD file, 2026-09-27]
mechanical/stl/support_moteur.STL
262.0 x 70.0 x 55.0

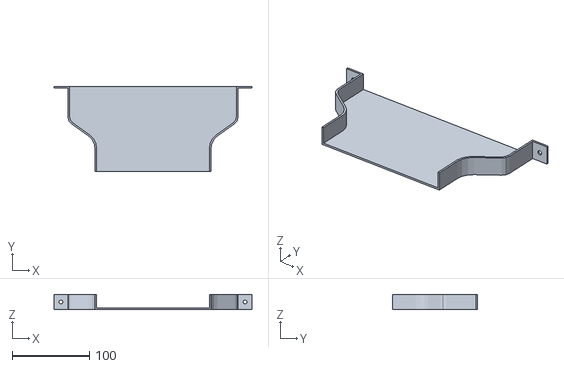
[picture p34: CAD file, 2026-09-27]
mechanical/stl/guide_soja.STL
256.0 x 110.0 x 20.0

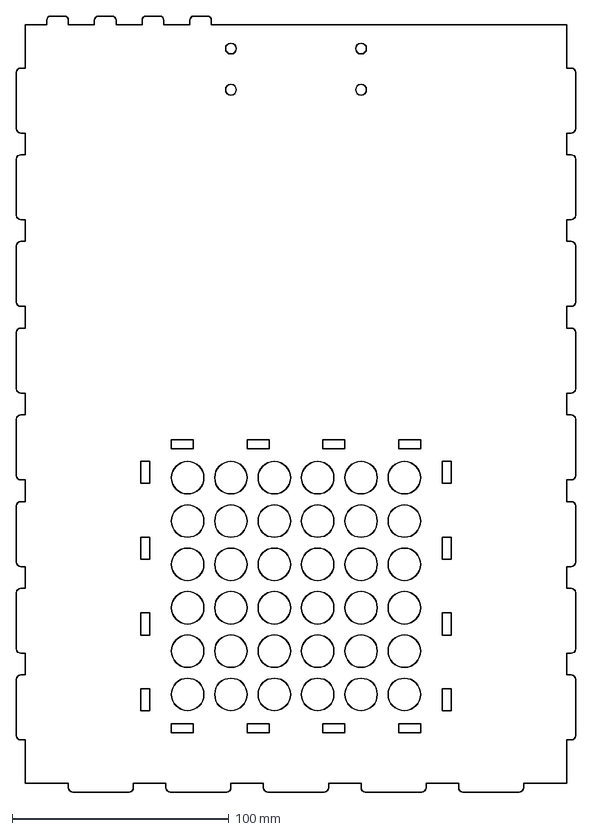
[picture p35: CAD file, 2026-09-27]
mechanical/drawings/Decoupe_Laser/sechage_face3.DXF
258.0 x 358.0 mm

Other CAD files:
mechanical/stl/support_vis_sans_fin.STL
mechanical/drawings/Decoupe_Laser/support_tamis_f2.DXF
mechanical/drawings/Decoupe_Laser/sechage_face9.DXF
mechanical/drawings/Decoupe_Laser/Etat déplié4 - plateau_support.DXF
mechanical/drawings/Decoupe_Laser/Etat déplié2 - plateau_support_X2.DXF
mechanical/drawings/Decoupe_Laser/Etat déplié3 - plateau_support_X2.DXF
mechanical/drawings/Decoupe_Laser/piedAR_support.DXF
mechanical/drawings/Decoupe_Laser/piedAV_support.DXF
mechanical/drawings/Decoupe_Laser/sechage_face1.DXF
mechanical/drawings/Decoupe_Laser/sechage_face10.DXF
mechanical/drawings/Decoupe_Laser/sechage_face2.DXF
mechanical/drawings/Decoupe_Laser/sechage_face6.DXF
mechanical/drawings/Decoupe_Laser/sechage_face7.DXF
mechanical/drawings/Decoupe_Laser/sechage_faceV1.DXF
mechanical/drawings/Decoupe_Laser/sechage_faceV1_3.DXF
mechanical/drawings/Decoupe_Laser/sechage_faceV1_4.DXF
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

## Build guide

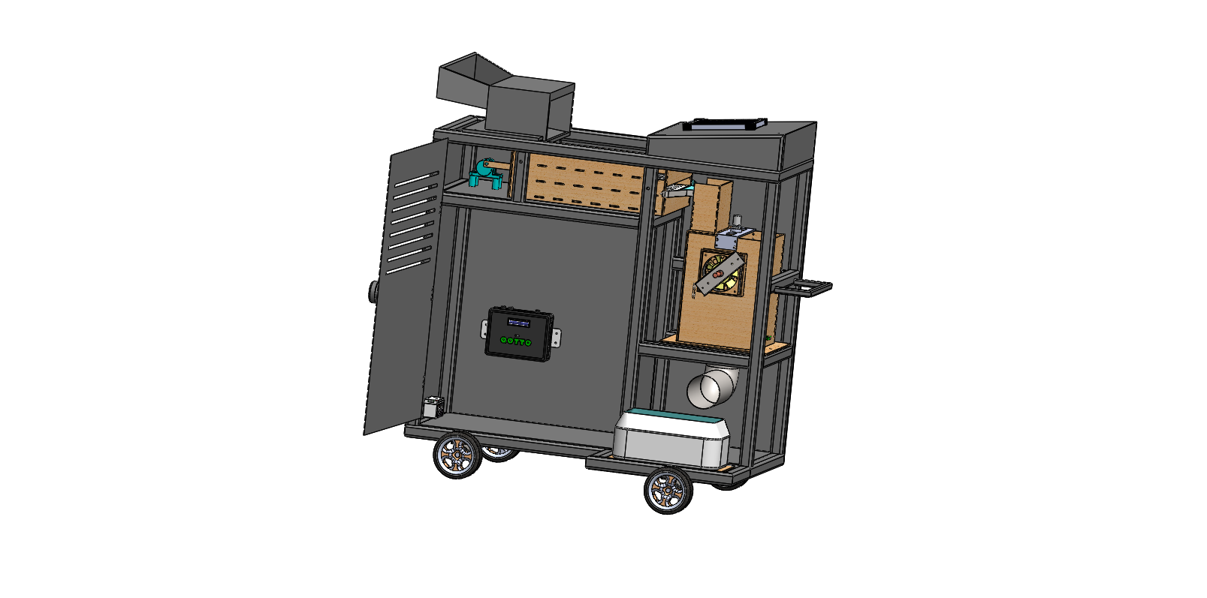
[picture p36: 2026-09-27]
mechanical/renders/Smart-Soja_Assemblage.PNG

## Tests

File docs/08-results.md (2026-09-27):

# Results

## Prototype physique réalisé

Vue d'ensemble du prototype

Le système est structuré en blocs physiques distincts montés sur un châssis en acier (tubes 30×30 mm) avec parois en contreplaqué, assurant à la fois la rigidité mécanique nécessaire aux vibrations du tamisage et l'isolation thermique requise pour le séchage. Détail des blocs assemblés : bloc d'entrée (trémie + servomoteur + IR), bloc de tamisage (cadre suspendu, moteur DC) et bloc de séchage actif (résistances 12 V, ventilateur, sondes capacitives, vis sans fin) — voir [04-mechanical-design.md](04-mechanical-design.md).

## Bilan des validations fonctionnelles

Le détail des tests est présenté dans [07-testing-validation.md](07-testing-validation.md). En synthèse :

1. **Acquisition de données** — DHT22 stable, sondes capacitives cohérentes avec l'état du soja, LCD fiable temps réel.
2. **Traitement et pilotage** — l'ESP32 exécute correctement la logique de contrôle (actionneurs, interface, sauvegarde locale).
3. **Actionneurs** — moteur de tamis, résistance chauffante, ventilateur et servomoteurs répondent tous correctement aux commandes.
4. **Traçabilité numérique** — génération de QR Code et transmission MQTT validées sur banc de test ; aucune perte de message ni payload JSON invalide n'a été observé pendant les essais documentés.
5. **Fonctions de sûreté et continuité** — arrêt d'urgence et mécanisme de sauvegarde locale / Store-and-Forward testés dans le périmètre du banc de validation.

## Limites de la validation actuelle

- **Cycle complet nettoyage + séchage** — testé composant par composant, pas encore en cycle opérationnel prolongé ; le taux de pureté et l'atteinte du seuil d'humidité cible ne sont pas encore quantifiés précisément.
- **Charge réelle** — tests réalisés sur de petites masses de soja de test ; le comportement en charge réelle (2 à 5 kg) reste à valider.
- **Conditions environnementales extrêmes** — tests en laboratoire stable uniquement ; robustesse terrain (poussière, vibrations, chaleur) non validée.
- **Autonomie réelle** — estimée à partir de mesures de courant isolées par sous-système, pas encore en cycle opérationnel complet.
- **Module de pesée (HX711)** — validation de précision et de stabilité prévue lors d'une phase d'intégration ultérieure.

## Voir aussi

- [07-testing-validation.md](07-testing-validation.md) — protocole et résultats détaillés par sous-système
- [09-future-improvements.md](09-future-improvements.md) — priorités avant déploiement opérationnel

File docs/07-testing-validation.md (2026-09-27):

# Testing & Validation

État à juin 2026 : phase d'assemblage et d'intégration. L'approche retenue démontre la faisabilité technique et la conformité des sous-systèmes **individuels** par des tests unitaires rigoureux, avant validation en cycle complet et en charge réelle (voir [09-future-improvements.md](09-future-improvements.md)).

## Méthodologie

Chaque sous-système suit un protocole en 4 étapes :
1. **Test unitaire** — activation isolée du composant, vérification du comportement attendu.
2. **Test d'intégration partielle** — assemblage provisoire avec composants dépendants (ex. DHT22 + LCD).
3. **Démonstration de la chaîne numérique** — acquisition → affichage → transmission → stockage local.
4. **Documentation des observations** — relevé systématique du comportement et des anomalies.

| Sous-système | Fonction testée | Instrument | Critère de validation |
|---|---|---|---|
| Moteur du tamis | Entraînement et vibration | Observation + multimètre | Rotation continue, absence de bruit anormal |
| Capteur DHT22 | Mesure T°C et humidité | Afficheur LCD | Valeurs en plage réaliste |
| Capteurs d'humidité | Mesure humidité soja | LCD + multimètre (ADC) | Signal cohérent avec l'état du soja |
| Résistance chauffante | Montée en température | DHT22 + multimètre | Chauffe observable, consommation mesurable |
| Ventilateur | Circulation d'air | Observation visuelle | Rotation et flux d'air présents |
| Interface LCD + WiFi | Affichage et transmission | Consultation + broker MQTT | Affichage clair, réception MQTT |

## Validation des capteurs

**DHT22** — relevés stables sur une session de 30 min (24,5→24,8 °C, 58,0→58,3 % HR, variation ≤ 0,3 sur les deux grandeurs). Conclusion : capteur opérationnel pour la supervision temps réel.

**Sondes capacitives Soil1/Soil2** — testées par immersion progressive dans du soja de test :

| État du soja | Soil1 (ADC) | Soil2 (ADC) |
|---|---|---|
| Très sec (stockage) | 280–300 | 285–305 |
| Humide (après exposition) | 450–480 | 460–490 |
| Saturé (test extrême) | 650–680 | 660–690 |

Variation linéaire en plage utile, écart inter-sonde < 10 points ADC (bonne reproductibilité). Capteurs opérationnels pour piloter le cycle de séchage.

## Validation du tamisage

Rotation moteur continue et stable, oscillation du cadre régulière, consommation 0,8–1,0 A / 12 V (≈ 10 W, conforme au nominal), pas de ralentissement ni de surcharge. Débris visiblement séparés après 2 à 3 cycles — le mécanisme fonctionne, un ou plusieurs cycles supplémentaires peuvent être nécessaires sur soja très humide ou encrassé pour un taux de pureté optimal.

## Validation du séchage

| Composant | Mesure | Conclusion |
|---|---|---|
| Résistance chauffante | Chauffe visible dès 10 s, très chaude à 30 s ; 1,0–1,2 A / 12 V (≈ 14 W) | Fonctionnel, conforme |
| Ventilateur | Rotation stable, flux d'air observable ; 0,6–0,8 A / 12 V (≈ 8 W) | Circulation d'air effective |
| Moteur de brassage | Rotation sans blocage, agitation observée | Homogénéisation possible |

Chauffe + ventilation produisent effectivement une circulation d'air chaud — le concept de séchage est validé. Limite : pas encore de mesure précise de la durée de séchage nécessaire pour atteindre la cible d'humidité.

## Validation du système énergétique

Tensions et courants mesurés au multimètre par sous-système :

| Mode / Charge | Courant (A) | Observation |
|---|---|---|
| Veille (LCD) | 0,12–0,15 | Consommation très faible |
| Acquisition DHT22 | 0,03–0,05 | Négligeable |
| Moteur du tamis | 0,8–1,0 | Stable, pas de surcharge |
| Résistance chauffante | 1,0–1,2 | Nominale, stable |
| Ventilateur | 0,6–0,8 | Sans problème |
| **Pic maximum (tous systèmes)** | **1,5** | Batterie maintient tension > 12 V |

Aucun effondrement de tension observé pendant les cycles de test. Le système est correctement dimensionné pour plusieurs heures d'utilisation normale (voir [06-energy-system.md](06-energy-system.md)).

## Validation de la traçabilité IoT

| Critère | Résultat |
|---|---|
| Format et structure JSON | Conforme aux spécifications |
| Publication MQTT | Aucune perte observée pendant les essais documentés en laboratoire |
| Latence de transmission | 200–300 ms (labo) |
| Intégrité des données | Aucun payload invalide observé pendant les essais documentés |
| Sauvegarde locale (SD) | Mécanisme Store-and-Forward validé sur banc de test |
| Génération QR Code | 5/5 générés avec succès |

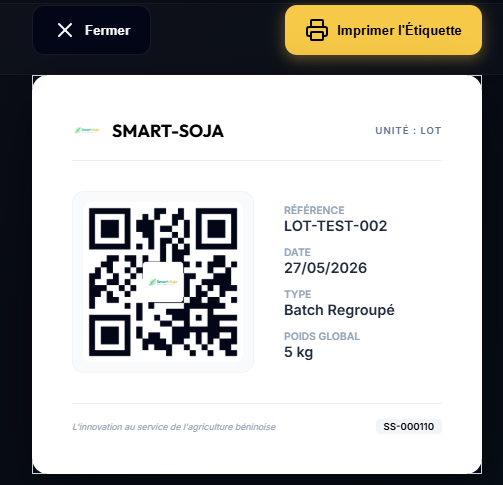
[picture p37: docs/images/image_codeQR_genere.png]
QR Code généré

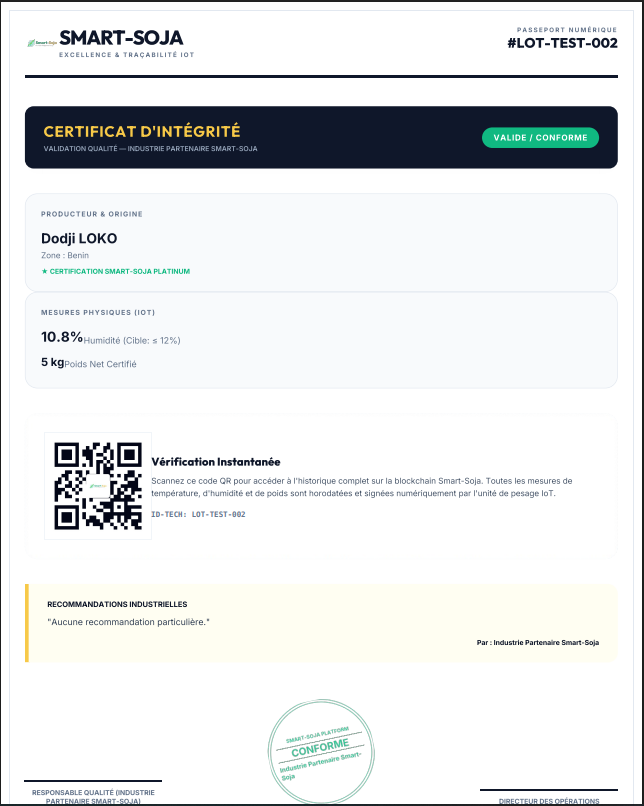
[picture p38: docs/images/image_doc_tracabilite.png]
Certificat de traçabilité


Le système génère un tableau de bord de supervision, une interface de configuration, une étiquette de lot avec QR Code et un certificat/passeport numérique. Cette chaîne documentaire a été validée sur le banc de test utilisé pendant le projet.

## Banc d'intégration

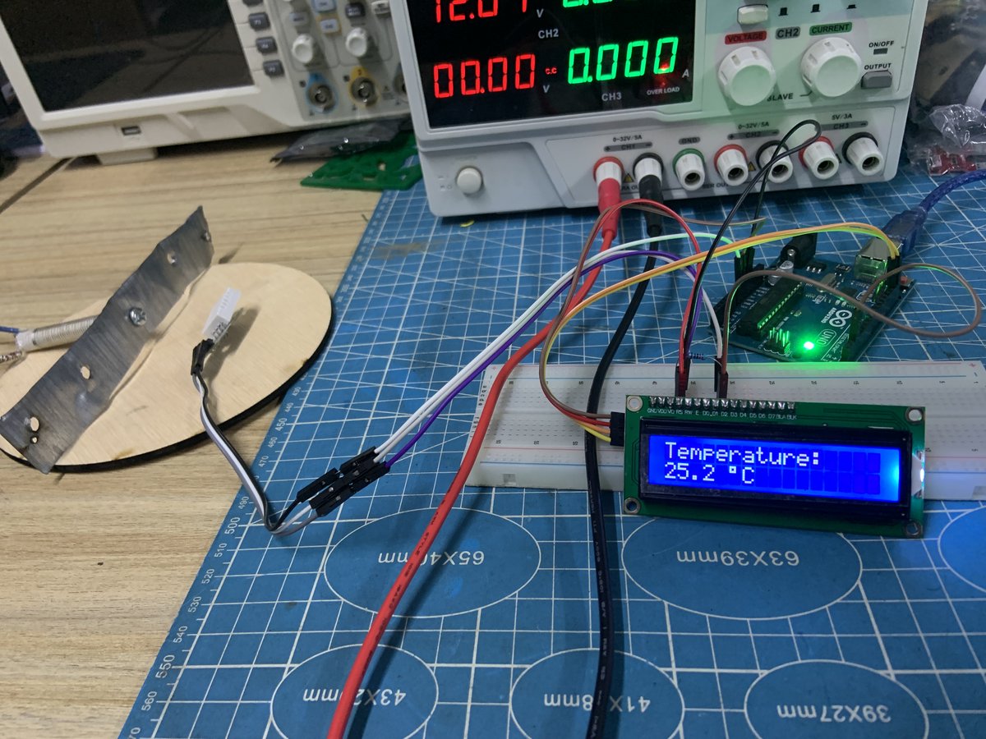
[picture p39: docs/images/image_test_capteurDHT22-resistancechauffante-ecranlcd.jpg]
Banc de test capteurs, résistance, LCD


## Synthèse

| Fonction | Statut |
|---|---|
| Moteur tamis | ✅ Opérationnel |
| Capteur DHT22 | ✅ Opérationnel |
| Sondes d'humidité | ✅ Opérationnel |
| Résistance chauffante | ✅ Opérationnel |
| Ventilateur | ✅ Opérationnel |
| Interface LCD | ✅ Opérationnel |
| Transmission MQTT | ✅ Opérationnel |
| Module de pesée (HX711) | ⏳ Intégration finale en cours |
| Cycle complet nettoyage + séchage en charge réelle | ⏳ À valider (2–5 kg) |

Les principaux sous-systèmes ont été validés individuellement et en intégration partielle. La chaîne numérique acquisition → traitement → affichage → transmission a fonctionné sur le banc de test ; cela ne constitue pas encore une validation du cycle mécanique complet sous charge réelle. Détail des limites et recommandations : [09-future-improvements.md](09-future-improvements.md).

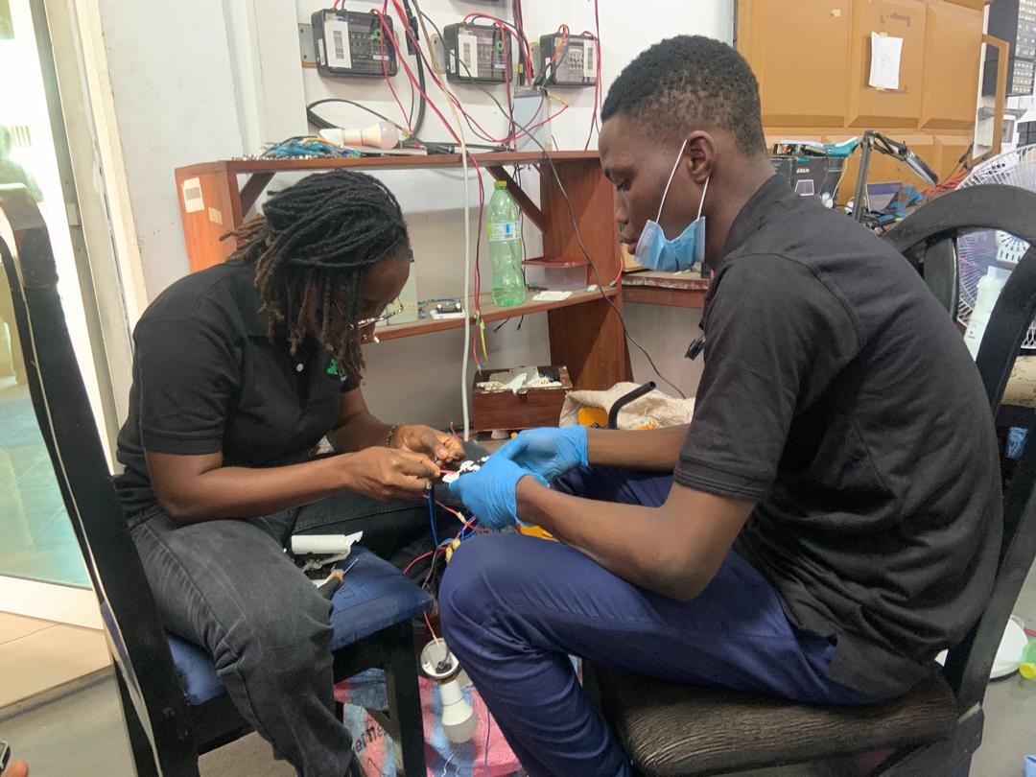
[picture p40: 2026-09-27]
media/prototype/image_test_lampe.jpeg

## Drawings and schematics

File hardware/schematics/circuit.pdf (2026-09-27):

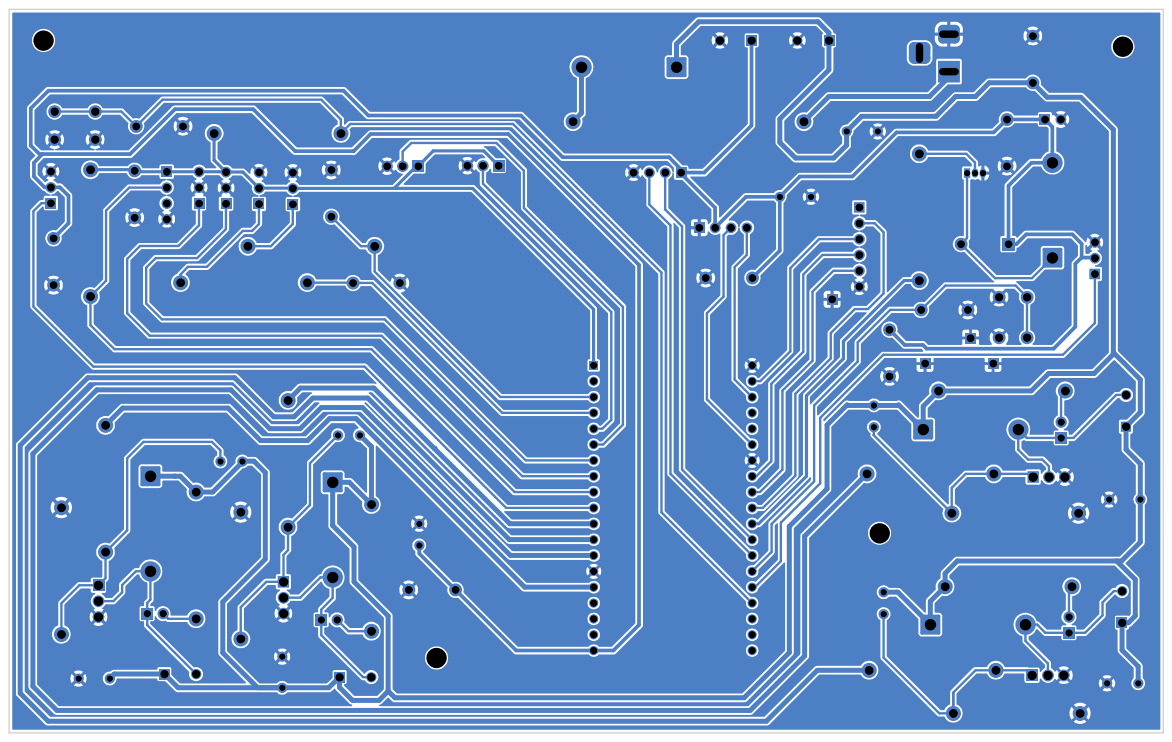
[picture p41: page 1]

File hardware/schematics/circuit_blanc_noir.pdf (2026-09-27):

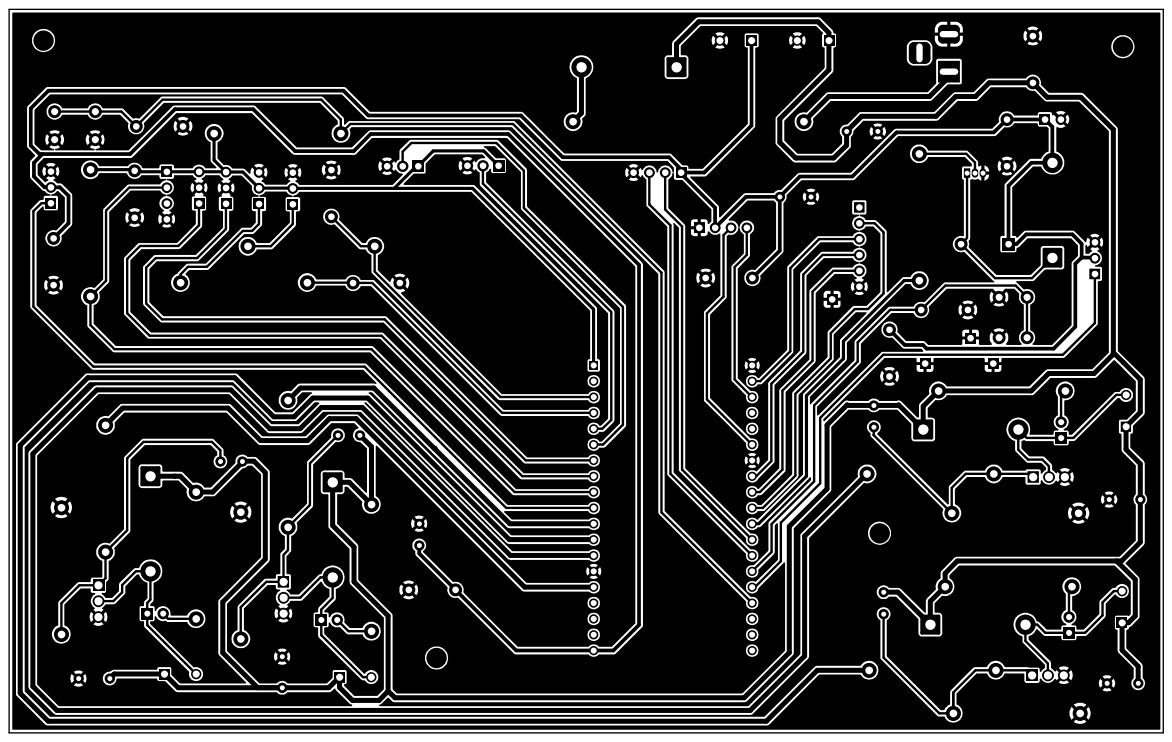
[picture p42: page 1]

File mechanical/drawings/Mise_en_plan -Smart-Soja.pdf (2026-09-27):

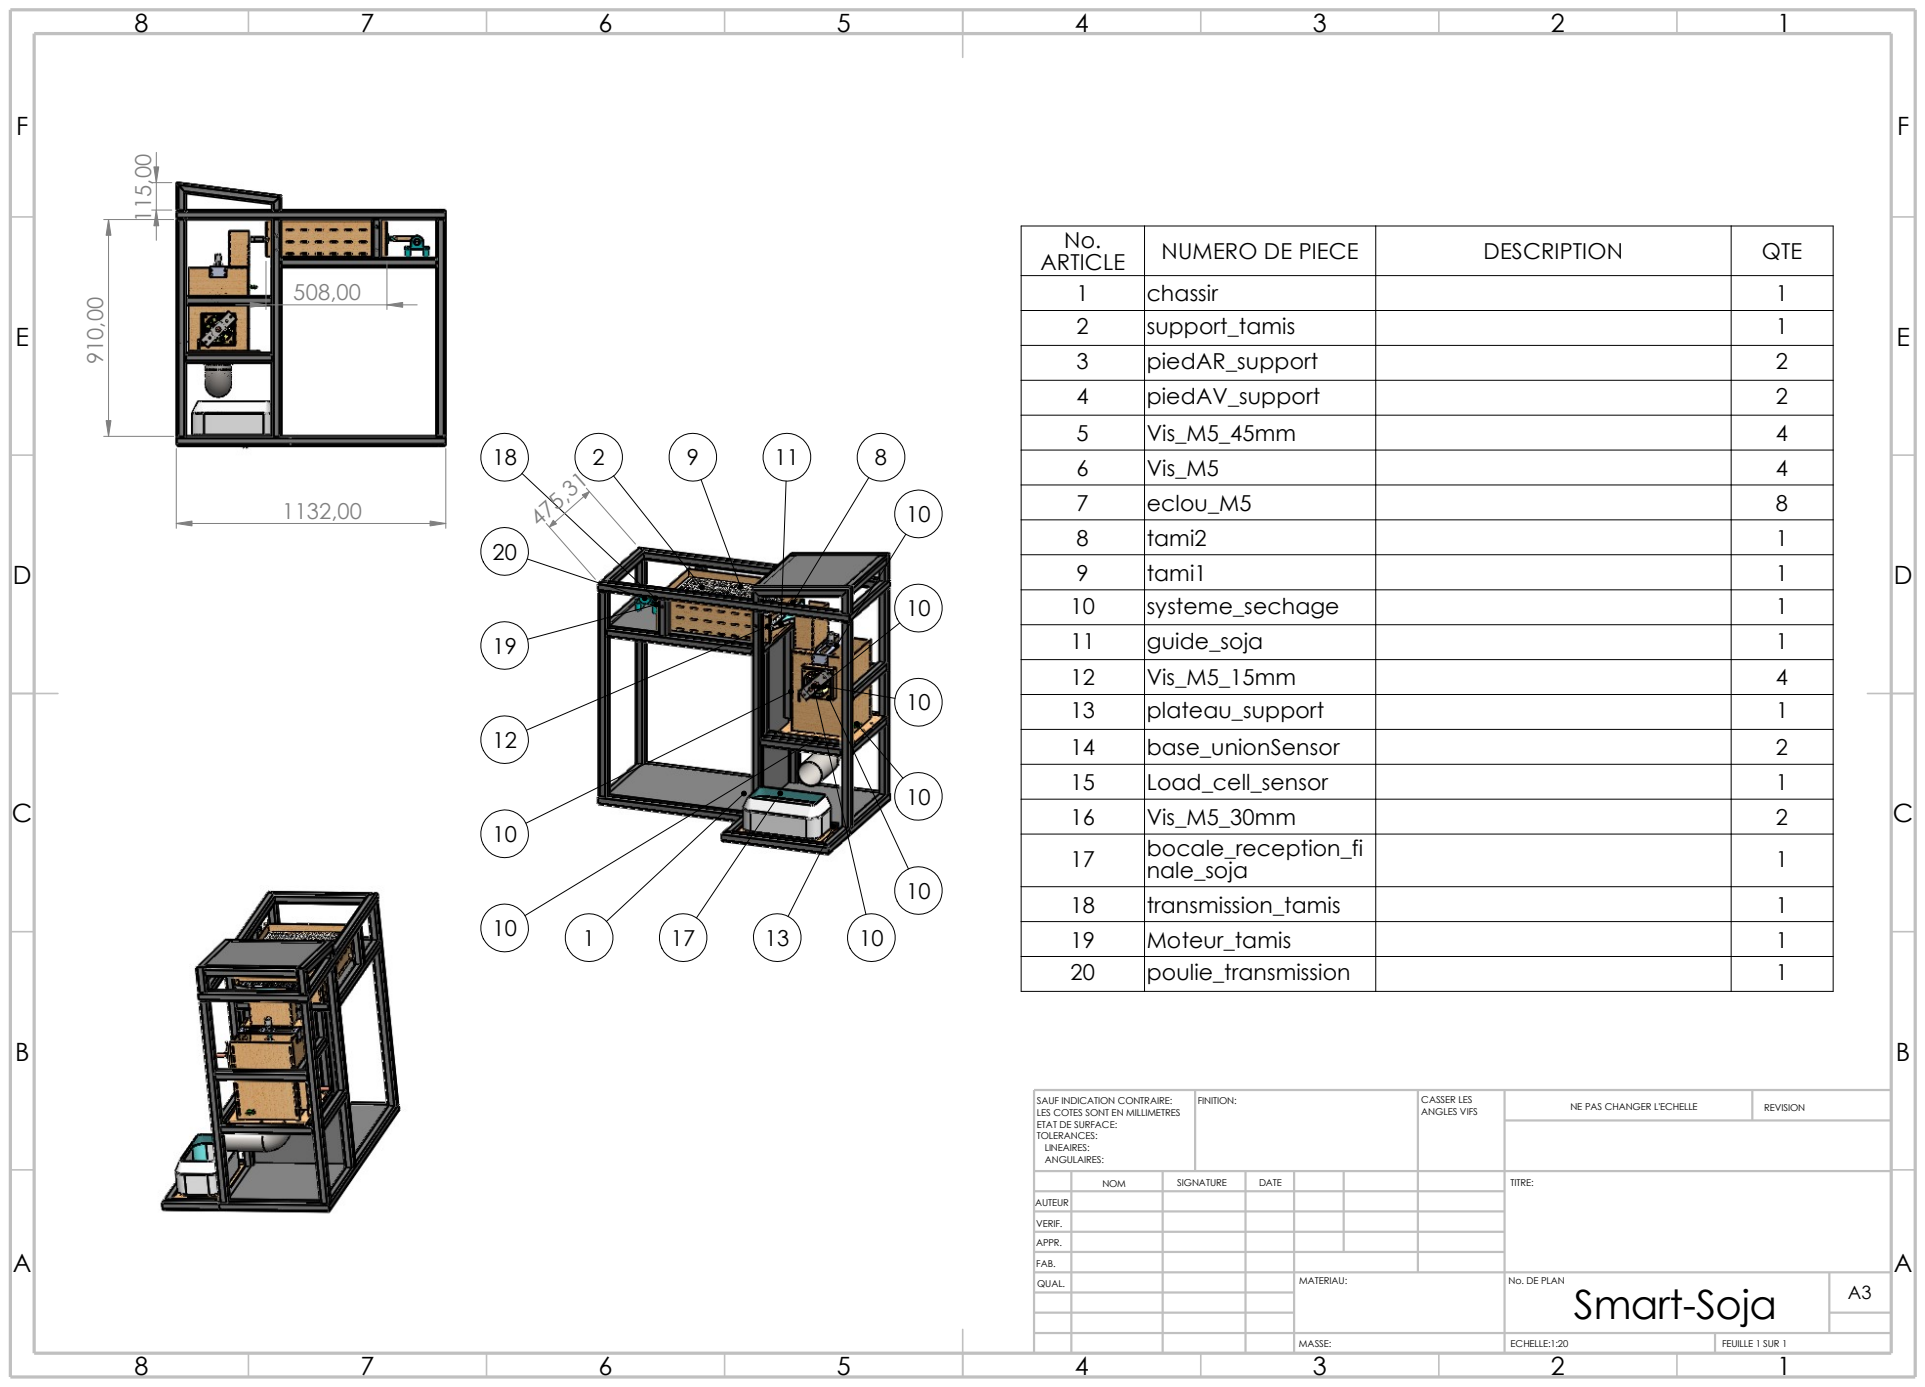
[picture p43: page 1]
ECHELLE:1:20; REVISION; FEUILLE 1 SUR 1; MASSE:; FINITION:; ANGLES VIFS; CASSER LES; 1132,00 ⁹¹⁰,00

No. ARTICLE | NUMERO DE PIECE | DESCRIPTION | QTE

1 | chassir | | 1
2 | support_tamis | | 1
3 | piedAR_support | | 2
4 | piedAV_support | | 2
5 | Vis_M5_45mm | | 4
6 | Vis_M5 | | 4
7 | eclou_M5 | | 8
8 | tami2 | | 1
9 | tami1 | | 1
10 | systeme_sechage | | 1
11 | guide_soja | | 1
12 | Vis_M5_15mm | | 4
13 | plateau_support | | 1
14 | base_unionSensor | | 2
15 | Load_cell_sensor | | 1
16 | Vis_M5_30mm | | 2
17 bocale_reception_fi | nale_soja | | 1

18 | transmission_tamis | | 1
19 | Moteur_tamis | | 1
20 | poulie_transmission | | 1

SAUF INDICATION CONTRAIRE:
LES COTES SONT EN MILLIMETRES
ETAT DE SURFACE:
TOLERANCES:
LINEAIRES:
ANGULAIRES:

NE PAS CHANGER L'ECHELLE

NOM | SIGNATURE | DATE | | | | TITRE:

AUTEUR
VERIF.
APPR.
QUAL. | | | | MATERIAU: | No. DE PLAN Smart-Soja | A3

FAB.

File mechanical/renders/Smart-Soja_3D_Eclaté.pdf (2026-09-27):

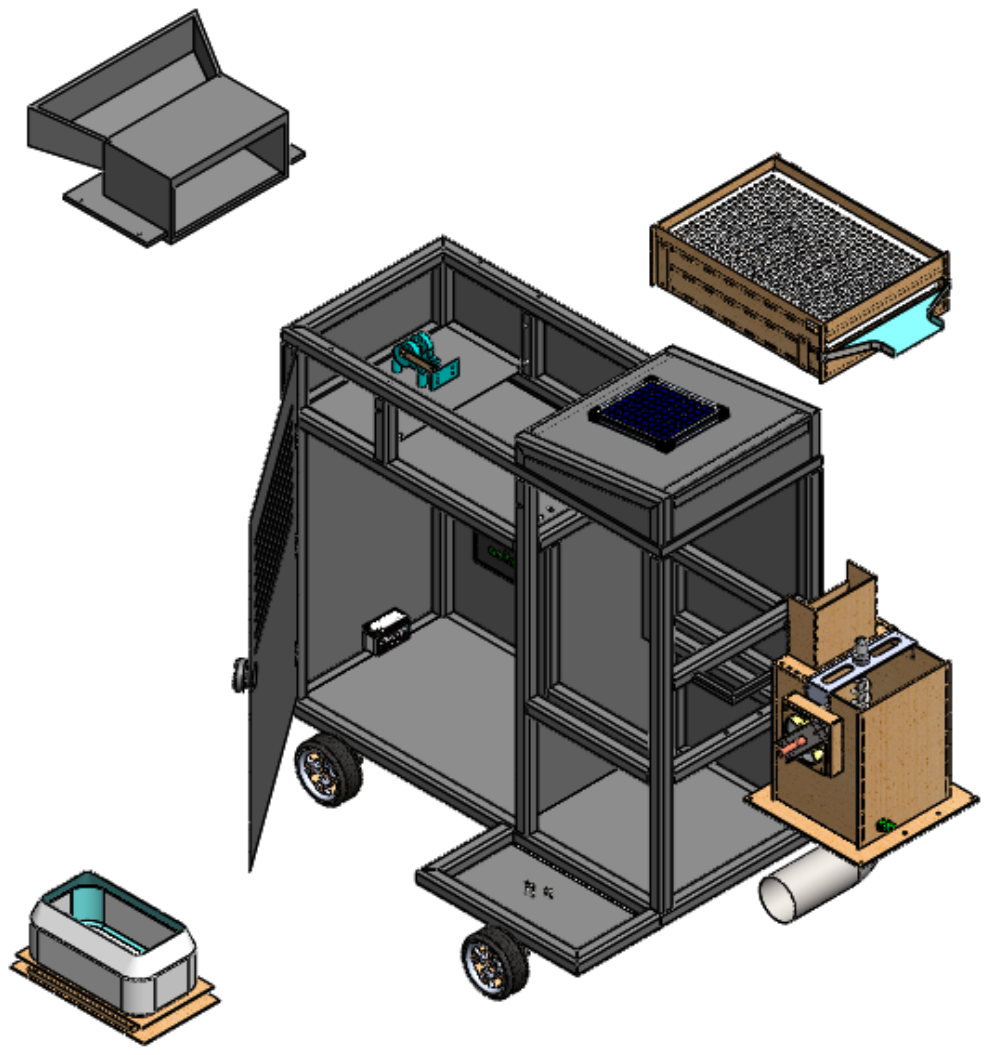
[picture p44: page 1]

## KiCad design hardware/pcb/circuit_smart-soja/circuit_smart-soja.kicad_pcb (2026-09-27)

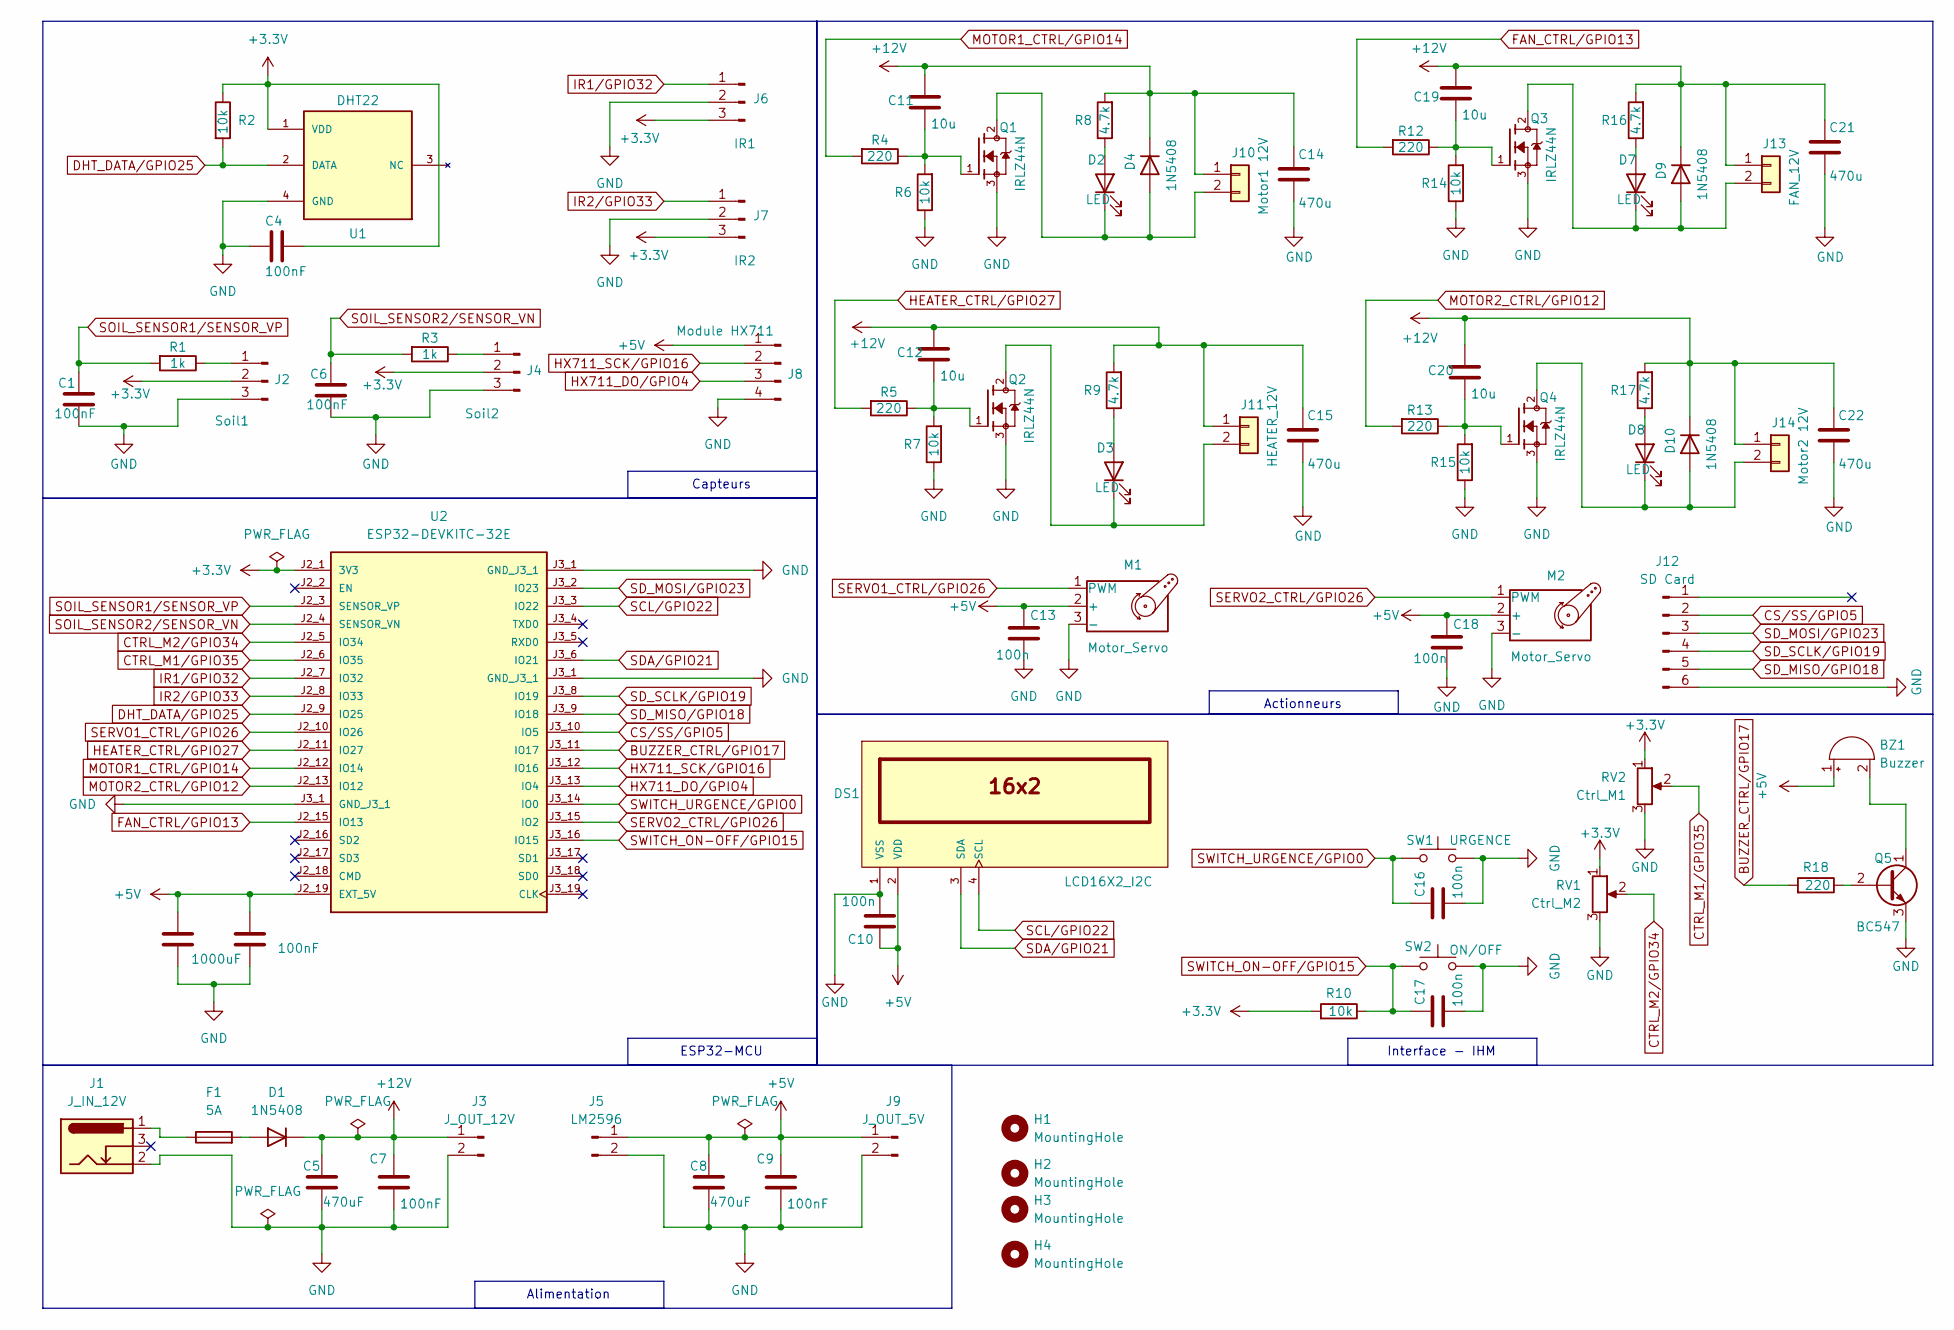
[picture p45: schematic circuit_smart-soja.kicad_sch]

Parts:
BZ1: Buzzer; Buzzer_12x9.5RM7.6
C1, C3, C4, C6, C7, C9: 100nF; C_Rect_L10.3mm_W4.5mm_P7.50mm_MKS4
C2: 1000uF; C_Radial_D8.0mm_H11.5mm_P3.50mm
C5, C8: 470uF; C_Radial_D10.0mm_H12.5mm_P5.00mm
C10, C13, C16, C17, C18: 100n; C_Rect_L10.3mm_W4.5mm_P7.50mm_MKS4
C11, C12, C19, C20: 10u; C_Radial_D8.0mm_H11.5mm_P3.50mm
C14, C15, C21, C22: 470u; C_Radial_D10.0mm_H12.5mm_P5.00mm
D1, D4, D9, D10: 1N5408; D_DO-201AD_P15.24mm_Horizontal
D2, D3, D7, D8: LED; LED_D3.0mm
DS1: LCD16X2_I2C; PinHeader_1x04_P2.54mm_Vertical
F1: 5A; Fuse_SunFuse-6HP
H1, H2, H3, H4: MountingHole; MountingHole_3.2mm_M3
J1: J_IN_12V; BarrelJack_Horizontal
J2: Soil1; PinHeader_1x03_P2.54mm_Vertical
J3: J_OUT_12V; TerminalBlock_Phoenix_MKDS-1,5-2-5.08_1x02_P5.08mm_Horizont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
J4: Soil2; PinHeader_1x03_P2.54mm_Vertical
J5: LM2596; TerminalBlock_Phoenix_MKDS-1,5-2-5.08_1x02_P5.08mm_Horizont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
J6: IR1; PinHeader_1x03_P2.54mm_Vertical
J7: IR2; PinHeader_1x03_P2.54mm_Vertical
J8: Module HX711; PinHeader_1x04_P2.54mm_Vertical
J9: J_OUT_5V; TerminalBlock_Phoenix_MKDS-1,5-2-5.08_1x02_P5.08mm_Horizont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
J10: Motor1 12V; TerminalBlock_Phoenix_MKDS-1,5-2-5.08_1x02_P5.08mm_Horizont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
J11: HEATER_12V; TerminalBlock_Phoenix_MKDS-1,5-2-5.08_1x02_P5.08mm_Horizont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
J12: SD Card; PinHeader_1x06_P2.54mm_Vertical
J13: FAN_12V; TerminalBlock_Phoenix_MKDS-1,5-2-5.08_1x02_P5.08mm_Horizont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
J14: Motor2 12V; TerminalBlock_Phoenix_MKDS-1,5-2-5.08_1x02_P5.08mm_Horizont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
M1, M2: Motor_Servo; PinHeader_1x03_P2.54mm_Vertical
Q1, Q2, Q3, Q4: IRLZ44N; TO-220-3_Vertical; PARTREV 11/11/03
Q5: BC547; TO-92L_HandSolder
R1, R3: 1k; R_Axial_DIN0414_L11.9mm_D4.5mm_P20.32mm_Horizontal
R2, R6, R7, R10, R14, R15: 10k; R_Axial_DIN0414_L11.9mm_D4.5mm_P20.32mm_Horizontal
R4, R5, R12, R13, R18: 220; R_Axial_DIN0414_L11.9mm_D4.5mm_P20.32mm_Horizontal
R8, R9, R16, R17: 4.7k; R_Axial_DIN0414_L11.9mm_D4.5mm_P20.32mm_Horizontal
RV1: Ctrl_M2; Potentiometer_Alps_RK163_Single_Horizontal
RV2: Ctrl_M1; Potentiometer_Alps_RK163_Single_Horizontal
SW1: URGENCE; SW_PUSH_6mm_H4.3mm
SW2: ON/OFF; SW_PUSH_6mm_H4.3mm
U1: DHT22; PinHeader_1x04_P2.54mm_Vertical
U2: ESP32-DEVKITC-32E; MODULE_ESP32-DEVKITC-32E; PARTREV 1.4

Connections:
+3.3V: C4.1, J2.2, J4.2, J6.3, J7.3, R2.1, R10.2, RV1.1, RV2.1, U1.1 (VDD), U2.J2_1 (3V3)
+5V: BZ1.1 (+), C2.1, C3.1, C8.1, C9.1, C10.1, C13.1, C18.1, DS1.2 (VDD), J5.1, J8.1, J9.1, M1.2 (+), M2.2 (+), U2.J2_19 (EXT_5V)
+12V: C5.1, C7.1, C11.1, C12.1, C14.1, C15.1, C19.1, C20.1, C21.1, C22.1, D1.1 (K), D4.1 (K), D9.1 (K), D10.1 (K), J3.1, J10.1, J11.1, J13.1, J14.1, R8.2, R9.2, R16.2, R17.2
BUZZER_CTRL/GPIO17: R18.2, U2.J3_11 (IO17)
CS/SS/GPIO5: J12.2, U2.J3_10 (IO5)
CTRL_M1/GPIO35: RV2.2, U2.J2_6 (IO35)
CTRL_M2/GPIO34: RV1.2, U2.J2_5 (IO34)
DHT_DATA/GPIO25: R2.2, U1.2 (DATA), U2.J2_9 (IO25)
FAN_CTRL/GPIO13: R12.2, U2.J2_15 (IO13)
GND: C1.2, C2.2, C3.2, C4.2, C5.2, C6.2, C7.2, C8.2, C9.2, C10.2, C13.2, C14.2, C15.2, C16.2, C17.2, C18.2, C21.2, C22.2, DS1.1 (VSS), J1.2, J2.3, J3.2, J4.3, J5.2, J6.2, J7.2, J8.4, J9.2, J12.6, M1.3 (-), M2.3 (-), Q1.3, Q2.3, Q3.3, Q4.3, Q5.3 (E), R6.1, R7.1, R14.1, R15.1, RV1.3, RV2.3, SW1.2, SW2.2, U1.4 (GND), U2.J3_1 (GND_J3_1)
HEATER_CTRL/GPIO27: R5.2, U2.J2_11 (IO27)
HX711_DO/GPIO4: J8.3, U2.J3_13 (IO4)
HX711_SCK/GPIO16: J8.2, U2.J3_12 (IO16)
IR1/GPIO32: J6.1, U2.J2_7 (IO32)
IR2/GPIO33: J7.1, U2.J2_8 (IO33)
MOTOR1_CTRL/GPIO14: R4.2, U2.J2_12 (IO14)
MOTOR2_CTRL/GPIO12: R13.2, U2.J2_13 (IO12)
unnamed: BZ1.2 (-), Q5.1 (C)
unnamed: C11.2, Q1.1, R4.1, R6.2
unnamed: C12.2, Q2.1, R5.1, R7.2
unnamed: C19.2, Q3.1, R12.1, R14.2
unnamed: C20.2, Q4.1, R13.1, R15.2
unnamed: D1.2 (A), F1.2
unnamed: D2.2 (A), R8.1
unnamed: D2.1 (K), D4.2 (A), J10.2, Q1.2
unnamed: D3.2 (A), R9.1
unnamed: D3.1 (K), J11.2, Q2.2
unnamed: D7.2 (A), R16.1
unnamed: D7.1 (K), D9.2 (A), J13.2, Q3.2
unnamed: D8.2 (A), R17.1
unnamed: D8.1 (K), D10.2 (A), J14.2, Q4.2
unnamed: F1.1, J1.1
unnamed: J2.1, R1.1
unnamed: J4.1, R3.1
unnamed: Q5.2 (B), R18.1
SCL/GPIO22: DS1.4 (SCL), U2.J3_3 (IO22)
SDA/GPIO21: DS1.3 (SDA), U2.J3_6 (IO21)
SD_MISO/GPIO18: J12.5, U2.J3_9 (IO18)
SD_MOSI/GPIO23: J12.3, U2.J3_2 (IO23)
SD_SCLK/GPIO19: J12.4, U2.J3_8 (IO19)
SERVO1_CTRL/GPIO26: M1.1 (PWM), U2.J2_10 (IO26)
SERVO2_CTRL/GPIO26: M2.1 (PWM), U2.J3_15 (IO2)
SOIL_SENSOR1/SENSOR_VP: C1.1, R1.2, U2.J2_3 (SENSOR_VP)
SOIL_SENSOR2/SENSOR_VN: C6.1, R3.2, U2.J2_4 (SENSOR_VN)
SWITCH_ON-OFF/GPIO15: C17.1, R10.1, SW2.1, U2.J3_16 (IO15)
SWITCH_URGENCE/GPIO0: C16.1, SW1.1, U2.J3_14 (IO0)

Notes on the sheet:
Interface - IHM
ESP32-MCU
Alimentation
Actionneurs
Capteurs

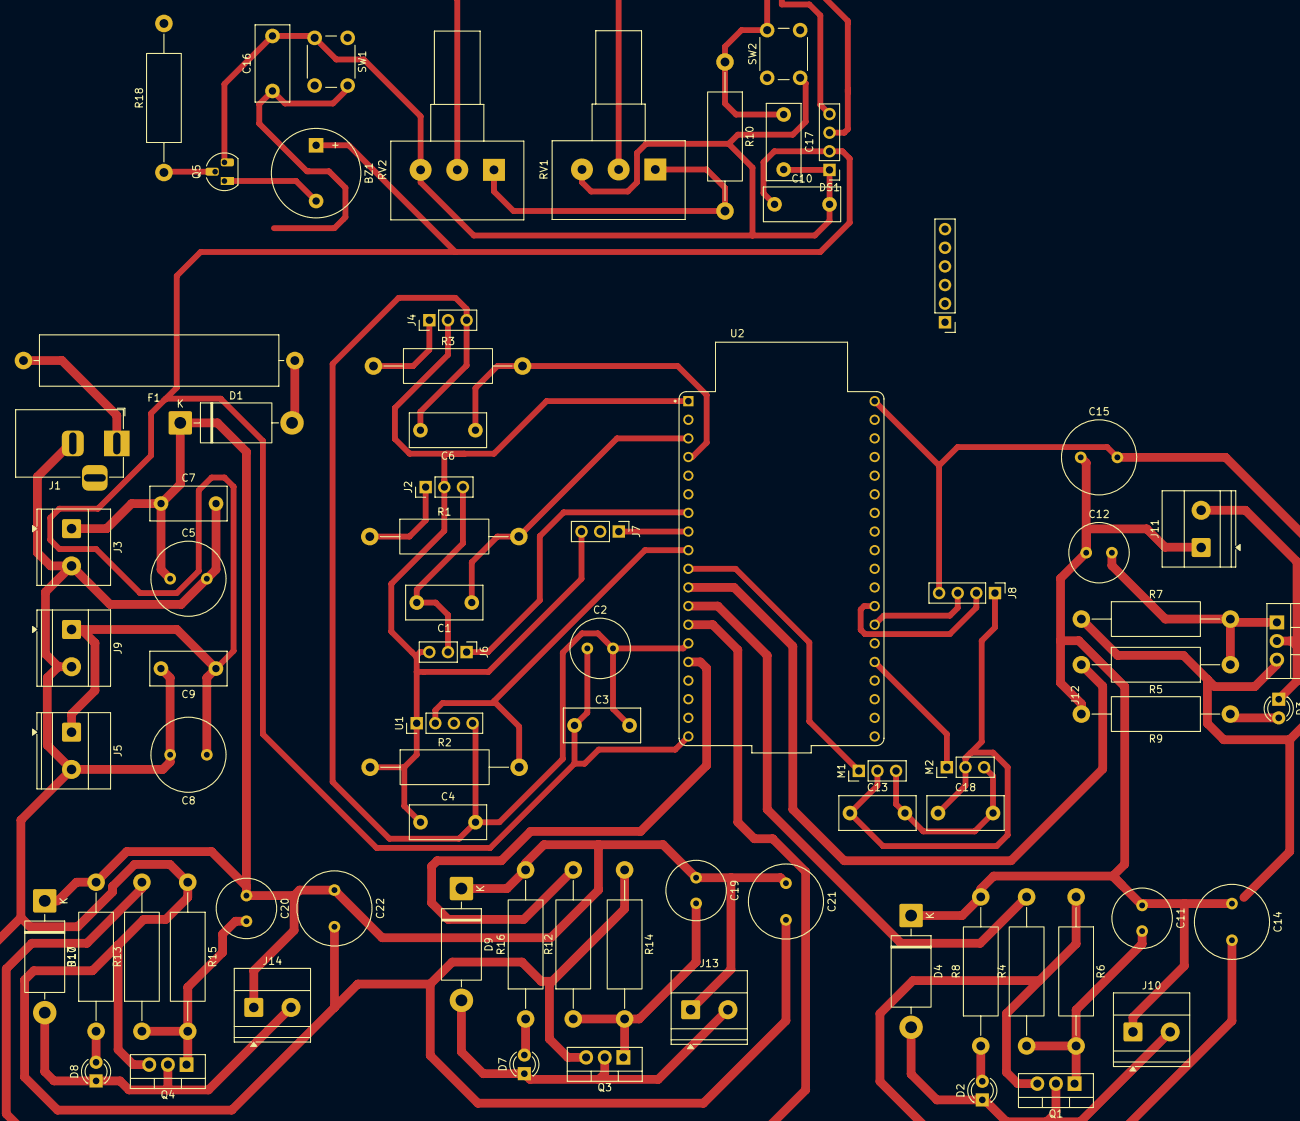
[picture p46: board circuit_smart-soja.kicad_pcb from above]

Board: 2 copper layers, 81 parts (0 on the bottom side), 46 nets.

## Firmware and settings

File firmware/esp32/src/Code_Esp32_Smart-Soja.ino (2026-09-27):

#include <Arduino.h>
#include <Wire.h>
#include <LiquidCrystal_I2C.h>
#include <ESP32Servo.h>
#include <DHT.h>
#include <WiFi.h>
#include <WiFiClientSecure.h>
#include <PubSubClient.h>
#include <ArduinoJson.h>
#include "secrets.h"  // Credentials WiFi & MQTT — fichier local ignoré par git

// ================= SERVOS =================
Servo servoTremie;
Servo servoVanne;

// ================= LCD =================
LiquidCrystal_I2C lcd(0x27, 16, 2);

// ================= DHT =================
#define PIN_DHT       25
#define DHTTYPE       DHT22
DHT dht(PIN_DHT, DHTTYPE);

// ================= WIFI & MQTT =================
// Les valeurs réelles sont dans src/secrets.h (ignoré par git).
// Copier secrets.example.h → secrets.h et remplir avant de compiler.
const char *ssid        = WIFI_SSID;
const char *password    = WIFI_PASSWORD;
const char *mqtt_server = MQTT_SERVER;
const int   mqtt_port   = MQTT_PORT;
const char *mqtt_user   = MQTT_USER;
const char *mqtt_pass   = MQTT_PASSWORD;

WiFiClientSecure espClient;
PubSubClient client(espClient);
String unit_id = "SS-LOCAL-01";

// ================= PINS =================
#define PIN_IR1           32
#define PIN_IR2           33

#define PIN_SOIL1         36
#define PIN_SOIL2         39

#define PIN_POT_TAMIS     35
#define PIN_POT_VIS       34

#define PIN_SERVO_TREMIE  26
#define PIN_SERVO_VANNE    2

#define PIN_MOTEUR_TAMIS  14
#define PIN_VIS_SANS_FIN  12

#define PIN_VENTILATEUR   13
#define PIN_RESISTANCE    27
#define PIN_BUZZER        17

#define PIN_START         15
#define PIN_STOP           0

// ================= SEUILS CAPTEURS =================
#define SOIL_ADC_MAX              1680
#define SEUIL_HUMIDITE_DEFAULT    120   // 12,0 % en dixièmes (compat MQTT plateforme)

// ================= SERVO TRÉMIE (rotation continue) =================
const int   TREMIE_ARRET         =  95;
const int   TREMIE_OUVRIR        =  65;
const int   TREMIE_FERMER        = 125;
const int   TREMIE_COUPLE_FERME  =  99;
const unsigned long TREMIE_T_OUVRIR  = 500;
const unsigned long TREMIE_T_FERMER  = 1000;

// ================= TIMINGS GRAFCET (ms) =================
unsigned long T_TAMIS     = 1000000;
unsigned long T_MESURE    =  5000;
unsigned long T_SECHAGE   =  5000;
unsigned long T_TRANSFERT =  5000;

// ================= PARAMÈTRES CONFIGURABLES =================
int seuil_humidite = SEUIL_HUMIDITE_DEFAULT;
int poids_cible_g = 100; // 100g par défaut
bool mode_manuel = false;

// ================= ETAPES GRAFCET =================
enum etape_t {
  E0_VEILLE,
  E2_TREMIE,
  E3_TAMIS,
  E4_HUMIDITE,
  E5_SECHAGE,
  E6_TRANSFERT,
  E7_PESEE,
  E8_ENREGISTREMENT,
  E9_SECURITE
};

// ================= VARIABLES PARTAGÉES =================
static portMUX_TYPE mux = portMUX_INITIALIZER_UNLOCKED;

volatile etape_t etape        = E0_VEILLE;
volatile float   temperature  = 0.0f;
volatile int     soil1_val    = 0;
volatile int     soil2_val    = 0;
volatile int     pot_tamis    = 0;
volatile int     pot_vis      = 0;
volatile float   poids        = 0.0f;
volatile bool    stop_cycle   = false;

// États des actionneurs pour la télémétrie
volatile bool state_alimentation = false;
volatile bool state_tamis = false;
volatile bool state_ventilo = false;
volatile bool state_heat = false;
volatile bool state_vis = false;
volatile bool state_vanne = false;

#define GET_ETAPE()  ({ portENTER_CRITICAL(&mux); etape_t _e = etape; portEXIT_CRITICAL(&mux); _e; })
#define SET_ETAPE(e) do { portENTER_CRITICAL(&mux); etape = (e); portEXIT_CRITICAL(&mux); } while(0)
#define GET_STOP()   ({ portENTER_CRITICAL(&mux); bool _s = stop_cycle; portEXIT_CRITICAL(&mux); _s; })
#define SET_STOP(v)  do { portENTER_CRITICAL(&mux); stop_cycle = (v); portEXIT_CRITICAL(&mux); } while(0)

// ================= HELPERS HUMIDITÉ =================
int adc_to_pct(int adc) {
  return constrain((adc * 100) / SOIL_ADC_MAX, 0, 100);
}

int compute_humidity_pct(int s1, int s2) {
  return max(adc_to_pct(s1), adc_to_pct(s2));
}

bool is_too_humid(int s1, int s2, int seuil_tenths) {
  return (compute_humidity_pct(s1, s2) * 10) > seuil_tenths;
}

// ================= HELPERS TRÉMIE =================
void tremie_ouvrir() {
  servoTremie.attach(PIN_SERVO_TREMIE);
  servoTremie.write(TREMIE_OUVRIR);
  vTaskDelay(pdMS_TO_TICKS(TREMIE_T_OUVRIR));
  servoTremie.write(TREMIE_ARRET);
  vTaskDelay(pdMS_TO_TICKS(50));
  servoTremie.detach();
}

void tremie_fermer() {
  servoTremie.attach(PIN_SERVO_TREMIE);
  servoTremie.write(TREMIE_FERMER);
  vTaskDelay(pdMS_TO_TICKS(TREMIE_T_FERMER));
  servoTremie.write(TREMIE_COUPLE_FERME);
}

// ================= SAFE STOP =================
void safe_stop() {
  ledcWrite(PIN_MOTEUR_TAMIS, 0);
  ledcWrite(PIN_VIS_SANS_FIN, 0);
  digitalWrite(PIN_VENTILATEUR, LOW);
  digitalWrite(PIN_RESISTANCE,  LOW);
  tremie_fermer();
  servoVanne.write(0);
  digitalWrite(PIN_BUZZER, HIGH);

  // Mettre à jour les états pour la télémétrie
  portENTER_CRITICAL(&mux);
  state_tamis = false;
  state_vis = false;
  state_ventilo = false;
  state_heat = false;
  state_alimentation = false;
  state_vanne = false;
  portEXIT_CRITICAL(&mux);
}

// ================= ACTUATEURS =================
void apply_actuators(etape_t e) {
  switch (e) {

    case E0_VEILLE:
      ledcWrite(PIN_MOTEUR_TAMIS, 0);
      ledcWrite(PIN_VIS_SANS_FIN, 0);
      digitalWrite(PIN_VENTILATEUR, LOW);
      digitalWrite(PIN_RESISTANCE,  LOW);
      servoVanne.write(0);
      digitalWrite(PIN_BUZZER, LOW);
      servoTremie.attach(PIN_SERVO_TREMIE);
      servoTremie.write(TREMIE_COUPLE_FERME);

      // Mettre à jour les états pour la télémétrie
      portENTER_CRITICAL(&mux);
      state_tamis = false;
      state_vis = false;
      state_ventilo = false;
      state_heat = false;
      state_alimentation = false;
      state_vanne = false;
      portEXIT_CRITICAL(&mux);
      break;

    case E2_TREMIE:
      tremie_ouvrir();

      // Mettre à jour les états pour la télémétrie
      portENTER_CRITICAL(&mux);
      state_alimentation = true;
      portEXIT_CRITICAL(&mux);
      break;

    case E3_TAMIS: {
      portENTER_CRITICAL(&mux);
      int spd = pot_tamis;
      portEXIT_CRITICAL(&mux);
      ledcWrite(PIN_MOTEUR_TAMIS, spd);

      // Mettre à jour les états pour la télémétrie
      portENTER_CRITICAL(&mux);
      state_tamis = true;
      state_alimentation = false;
      portEXIT_CRITICAL(&mux);
      break;
    }

    case E4_HUMIDITE:
      ledcWrite(PIN_MOTEUR_TAMIS, 0);

      // Mettre à jour les états pour la télémétrie
      portENTER_CRITICAL(&mux);
      state_tamis = false;
      portEXIT_CRITICAL(&mux);
      break;

    case E5_SECHAGE: {
      digitalWrite(PIN_VENTILATEUR, HIGH);
      digitalWrite(PIN_RESISTANCE,  HIGH);
      portENTER_CRITICAL(&mux);
      int spd = pot_vis;
      portEXIT_CRITICAL(&mux);
      ledcWrite(PIN_VIS_SANS_FIN, spd);

      // Mettre à jour les états pour la télémétrie
      portENTER_CRITICAL(&mux);
      state_ventilo = true;
      state_heat = true;
      state_vis = true;
      portEXIT_CRITICAL(&mux);
      break;
    }

    case E6_TRANSFERT:
      digitalWrite(PIN_VENTILATEUR, LOW);
      digitalWrite(PIN_RESISTANCE,  LOW);
      ledcWrite(PIN_VIS_SANS_FIN, 0);
      servoVanne.write(90);

      // Mettre à jour les états pour la télémétrie
      portENTER_CRITICAL(&mux);
      state_ventilo = false;
      state_heat = false;
      state_vis = false;
      state_vanne = true;
      portEXIT_CRITICAL(&mux);
      break;

    case E7_PESEE:
      // Mettre à jour les états pour la télémétrie
      portENTER_CRITICAL(&mux);
      state_vanne = false;
      portEXIT_CRITICAL(&mux);
      break;

    case E8_ENREGISTREMENT:
      servoVanne.write(0);
      tremie_fermer();

      // Mettre à jour les états pour la télémétrie
      portENTER_CRITICAL(&mux);
      state_alimentation = false;
      portEXIT_CRITICAL(&mux);
      break;

    case E9_SECURITE:
      safe_stop();
      break;
  }
}

// ================= TÂCHE GRAFCET =================
void task_grafcet(void *pv) {

  unsigned long t_etape = 0;
  etape_t       last_e  = E9_SECURITE;

  for (;;) {

    etape_t e = GET_ETAPE();

    // En mode manuel, le GRAFCET ne gère pas les transitions automatiques
    portENTER_CRITICAL(&mux);
    bool manual_mode = mode_manuel;
    portEXIT_CRITICAL(&mux);

    if (e != last_e) {
      apply_actuators(e);
      t_etape = millis();
      last_e  = e;
    }

    bool ir1  = (digitalRead(PIN_IR1) == LOW);   // LOW = détecte soja
    bool ir2  = (digitalRead(PIN_IR2) == LOW);   // LOW = détecte soja
    bool stop = GET_STOP();

    portENTER_CRITICAL(&mux);
    int   s1  = soil1_val;
    int   s2  = soil2_val;
    float pds = poids;
    int   seuil_h = seuil_humidite;
    int   poids_cible = poids_cible_g;
    unsigned long t_tamis = T_TAMIS;
    unsigned long t_mesure = T_MESURE;
    unsigned long t_sechage = T_SECHAGE;
    unsigned long t_transfert = T_TRANSFERT;
    portEXIT_CRITICAL(&mux);

    unsigned long dt = millis() - t_etape;

    // En mode manuel, on ne traite que l'arrêt d'urgence
    if (manual_mode) {
      if (stop) {
        SET_ETAPE(E9_SECURITE);
      }
      vTaskDelay(pdMS_TO_TICKS(100));
      continue;
    }

    switch (e) {

      case E0_VEILLE:
        // START=LOW (pressé, pullup externe) + IR1 détecte + IR2 détecte + pas de stop
        if (ir1 && ir2 && !stop)
          SET_ETAPE(E2_TREMIE);
        break;

      case E2_TREMIE:
        if (stop)
          SET_ETAPE(E9_SECURITE);
        else
          SET_ETAPE(E3_TAMIS);
        break;

      case E3_TAMIS:
{
    portENTER_CRITICAL(&mux);
    int spd = pot_tamis;
    portEXIT_CRITICAL(&mux);

    ledcWrite(PIN_MOTEUR_TAMIS, spd);

    if (dt >= t_tamis && !stop)
        SET_ETAPE(E4_HUMIDITE);
    else if (stop)
        SET_ETAPE(E9_SECURITE);

    break;
}

      case E4_HUMIDITE:
        if (stop) { SET_ETAPE(E9_SECURITE); break; }
        if (dt >= t_mesure) {
          bool humide = is_too_humid(s1, s2, seuil_h);
          SET_ETAPE(humide ? E5_SECHAGE : E6_TRANSFERT);
        }
        break;

      case E5_SECHAGE:
{
    portENTER_CRITICAL(&mux);
    int spd = pot_vis;
    portEXIT_CRITICAL(&mux);

    ledcWrite(PIN_VIS_SANS_FIN, spd);

    if (dt >= t_sechage)
        SET_ETAPE(E4_HUMIDITE);

    break;
}

      case E6_TRANSFERT:
        if (stop) { SET_ETAPE(E9_SECURITE); break; }
        if (dt >= t_transfert)
          SET_ETAPE(E7_PESEE);
        break;

      case E7_PESEE:
  if (stop) { SET_ETAPE(E9_SECURITE); break; }
  // Simulation : après 3 secondes, on attribue un poids aléatoire entre 100g et 500g
  if (dt >= 3000 && pds == 0.0f) {
    float simPoids = 100.0f + (float)(esp_random() % 401); // 100..500g
    portENTER_CRITICAL(&mux);
    poids = simPoids;
    portEXIT_CRITICAL(&mux);
    Serial.printf("[PESEE] Poids simulé : %.1f g\n", simPoids);
  }
  if (pds >= (float)poids_cible)
    SET_ETAPE(E8_ENREGISTREMENT);
  break;

      case E8_ENREGISTREMENT:
  if (stop) { SET_ETAPE(E9_SECURITE); break; }
  if (!ir2) {  // ir2=false → soja évacué
    portENTER_CRITICAL(&mux);
    poids = 0.0f;  // reset pour le prochain cycle
    portEXIT_CRITICAL(&mux);
    SET_ETAPE(E0_VEILLE);
  }
  break;

      case E9_SECURITE:
        safe_stop();
        break;
    }

    vTaskDelay(pdMS_TO_TICKS(100));
  }
}

// ================= TÂCHE CAPTEURS =================
void task_sensors(void *pv) {

  static float last_t = 25.0f;

  for (;;) {

    int s1 = analogRead(PIN_SOIL1);
    int s2 = analogRead(PIN_SOIL2);

    int pt = map(analogRead(PIN_POT_TAMIS), 0, 4095, 0, 255);
    int pv = map(analogRead(PIN_POT_VIS),   0, 4095, 0, 255);

    float t = dht.readTemperature();
    if (!isnan(t))
      last_t = (last_t * 0.7f) + (t * 0.3f);

    // STOP : LOW = bouton pressé (logique normale avec INPUT_PULLUP)
    bool stop_now = (digitalRead(PIN_STOP) == LOW);

    portENTER_CRITICAL(&mux);
    soil1_val   = s1;
    soil2_val   = s2;
    pot_tamis   = pt;
    pot_vis     = pv;
    temperature = last_t;
    stop_cycle  = stop_now;
    portEXIT_CRITICAL(&mux);

    vTaskDelay(pdMS_TO_TICKS(1500));
  }
}

// ================= TÂCHE LCD =================
void task_lcd(void *pv) {

  for (;;) {

    etape_t e = GET_ETAPE();

    portENTER_CRITICAL(&mux);
    float temp = temperature;
    int   s1   = soil1_val;
    int   s2   = soil2_val;
    portEXIT_CRITICAL(&mux);

    int hum_pct = compute_humidity_pct(s1, s2);

    lcd.setCursor(0, 0);
    switch (e) {
      case E0_VEILLE:          lcd.print("VEILLE          "); break;
      case E2_TREMIE:          lcd.print("TREMIE          "); break;
      case E3_TAMIS:           lcd.print("TAMIS           "); break;
      case E4_HUMIDITE:        lcd.print("HUMIDITE        "); break;
      case E5_SECHAGE:         lcd.print("SECHAGE         "); break;
      case E6_TRANSFERT:       lcd.print("TRANSFERT       "); break;
      case E7_PESEE:           lcd.print("PESEE           "); break;
      case E8_ENREGISTREMENT:  lcd.print("ENREG.          "); break;
      case E9_SECURITE:        lcd.print("!! ARRET !!     "); break;
    }

    lcd.setCursor(0, 1);
    lcd.print("T:");
    lcd.print((int)temp);
    lcd.print("C H:");
    lcd.print(hum_pct);
    lcd.print("%   ");

    vTaskDelay(pdMS_TO_TICKS(500));
  }
}

// ================= WIFI & MQTT =================
void configurer_wifi_mqtt() {
  WiFi.begin(ssid, password);
  Serial.print("Connexion WiFi");
  while (WiFi.status() != WL_CONNECTED) {
    delay(500);
    Serial.print(".");
  }
  Serial.println("\nWiFi connecté!");
  Serial.print("IP: ");
  Serial.println(WiFi.localIP());

  // Générer unit_id basé sur MAC
  unit_id = "SS-" + String(WiFi.macAddress().substring(12));

  espClient.setInsecure(); // Nécessaire pour HiveMQ Cloud sans certificat racine
  client.setServer(mqtt_server, mqtt_port);
}

void callback_mqtt(char *topic, byte *payload, unsigned int length) {
  StaticJsonDocument<512> doc;
  DeserializationError error = deserializeJson(doc, payload, length);
  if (error) {
    Serial.println("Erreur de désérialisation JSON");
    return;
  }

  // Gestion des commandes
  if (doc.containsKey("mode")) {
    String modeStr = doc["mode"].as<String>();
    if (modeStr == "auto") {
      Serial.println("Mode: AUTOMATIQUE");
      portENTER_CRITICAL(&mux);
      mode_manuel = false;
      portEXIT_CRITICAL(&mux);
      if (doc.containsKey("action") && doc["action"].as<String>() == "cycle_start") {
        // Démarrer le cycle
        if (GET_ETAPE() == E0_VEILLE) {
          SET_ETAPE(E2_TREMIE);
        }
      }
    } else if (modeStr == "manual") {
      Serial.println("Mode: MANUEL");
      portENTER_CRITICAL(&mux);
      mode_manuel = true;
      portEXIT_CRITICAL(&mux);
      // En mode manuel, on peut contrôler les actionneurs individuellement
    }
  }

  // Contrôle manuel des actionneurs
  if (mode_manuel && doc.containsKey("action") && doc["action"].as<String>() == "control_manual") {
    String device = doc["device"].as<String>();
    String state = doc["state"].as<String>();
    bool active = (state == "ON");

    Serial.printf("Commande manuelle: %s -> %s\n", device.c_str(), state.c_str());

    portENTER_CRITICAL(&mux);

    if (device == "servo_tremie") {
      if (active) {
        tremie_ouvrir();
        state_alimentation = true;
      } else {
        tremie_fermer();
        state_alimentation = false;
      }
    } else if (device == "tamis") {
      int spd = active ? pot_tamis : 0;
      ledcWrite(PIN_MOTEUR_TAMIS, spd);
      state_tamis = active;
    } else if (device == "ventilateur") {
      digitalWrite(PIN_VENTILATEUR, active ? HIGH : LOW);
      state_ventilo = active;
    } else if (device == "chauffage") {
      digitalWrite(PIN_RESISTANCE, active ? HIGH : LOW);
      state_heat = active;
    } else if (device == "vis_soja") {
      int spd = active ? pot_vis : 0;
      ledcWrite(PIN_VIS_SANS_FIN, spd);
      state_vis = active;
    } else if (device == "servo_vanne") {
      servoVanne.write(active ? 90 : 0);
      state_vanne = active;
    }

    portEXIT_CRITICAL(&mux);
  }

  if (doc.containsKey("action") && doc["action"].as<String>() == "emergency_stop") {
    SET_STOP(true);
    Serial.println("Arrêt d'urgence reçu via MQTT");
  }

  if (doc.containsKey("config")) {
    JsonObject config = doc["config"];

    portENTER_CRITICAL(&mux);

    if (config.containsKey("seuil_humidite")) {
      seuil_humidite = config["seuil_humidite"];
      Serial.printf("Seuil humidité mis à jour: %.1f %%\n", seuil_humidite / 10.0f);
    }
    if (config.containsKey("poids_cible")) {
      poids_cible_g = config["poids_cible"];
      Serial.printf("Poids cible mis à jour: %d g\n", poids_cible_g);
    }
    if (config.containsKey("temps_tamis_ms")) {
      T_TAMIS = config["temps_tamis_ms"];
      Serial.printf("Temps tamis mis à jour: %lu ms\n", T_TAMIS);
    }
    if (config.containsKey("temps_mesure_ms")) {
      T_MESURE = config["temps_mesure_ms"];
      Serial.printf("Temps mesure mis à jour: %lu ms\n", T_MESURE);
    }
    if (config.containsKey("temps_sechage_ms")) {
      T_SECHAGE = config["temps_sechage_ms"];
      Serial.printf("Temps séchage mis à jour: %lu ms\n", T_SECHAGE);
    }
    if (config.containsKey("temps_transfert_ms")) {
      T_TRANSFERT = config["temps_transfert_ms"];
      Serial.printf("Temps transfert mis à jour: %lu ms\n", T_TRANSFERT);
    }

    portEXIT_CRITICAL(&mux);

    Serial.println("Configuration appliquée");
  }
}

void task_mqtt(void *pv) {
  unsigned long timer_telemetrie = 0;

  for (;;) {
    // Connexion MQTT
    if (!client.connected()) {
      Serial.println("Tentative de connexion MQTT...");
      if (client.connect(("SmartSoja_" + unit_id).c_str(), mqtt_user, mqtt_pass)) {
        Serial.println("MQTT Connecté !");
        client.subscribe(("smart-soja/commands/" + unit_id).c_str());
        client.setCallback(callback_mqtt);
      } else {
        Serial.print("Échec, rc=");
        Serial.print(client.state());
        Serial.println(" retry in 5s");
      }
    }

    client.loop();

    // Envoi télémétrie toutes les 5 secondes
    if (millis() - timer_telemetrie >= 5000) {
      timer_telemetrie = millis();

      StaticJsonDocument<512> doc;
      doc["unitId"] = unit_id;
      doc["step"] = (int)GET_ETAPE();
      
      portENTER_CRITICAL(&mux);
      int s1 = soil1_val;
      int s2 = soil2_val;
      doc["humidity"] = compute_humidity_pct(s1, s2);
      doc["humidity_s1"] = adc_to_pct(s1);
      doc["humidity_s2"] = adc_to_pct(s2);
      doc["temperature"] = temperature;
      doc["weight"] = poids;
      doc["alarm"] = GET_STOP();
      doc["ir1"] = (digitalRead(PIN_IR1) == LOW);
      doc["ir2"] = (digitalRead(PIN_IR2) == LOW);
      
      JsonObject controls = doc.createNestedObject("controls");
      controls["alimentation"] = state_alimentation;
      controls["tamis"] = state_tamis;
      controls["ventilo"] = state_ventilo;
      controls["heat"] = state_heat;
      controls["vis"] = state_vis;
      controls["vanne"] = state_vanne;
      portEXIT_CRITICAL(&mux);

      String payload;
      serializeJson(doc, payload);
      String topic = "smart-soja/telemetry/" + unit_id;

      if (client.connected()) {
        client.publish(topic.c_str(), payload.c_str());
        Serial.println("Télémétrie envoyée: " + payload);
      }
    }

    vTaskDelay(pdMS_TO_TICKS(100));
  }
}

// ================= SETUP =================
void setup() {

  Serial.begin(115200);

  Wire.begin(21, 22);
  lcd.begin();
  lcd.backlight();
  lcd.clear();
  lcd.print("INIT SYSTEM");

  pinMode(PIN_START,       INPUT);   // pullup externe sur la carte
  pinMode(PIN_STOP,        INPUT_PULLUP);  // repos=HIGH, pressé=LOW
  pinMode(PIN_IR1,         INPUT);
  pinMode(PIN_IR2,         INPUT);

  pinMode(PIN_VENTILATEUR, OUTPUT);
  pinMode(PIN_RESISTANCE,  OUTPUT);
  pinMode(PIN_BUZZER,      OUTPUT);

  digitalWrite(PIN_VENTILATEUR, LOW);
  digitalWrite(PIN_RESISTANCE,  LOW);
  digitalWrite(PIN_BUZZER,      LOW);

  servoTremie.attach(PIN_SERVO_TREMIE);
  servoTremie.write(TREMIE_COUPLE_FERME);

  servoVanne.attach(PIN_SERVO_VANNE);
  servoVanne.write(0);

  ledcAttach(PIN_MOTEUR_TAMIS, 5000, 8);
  ledcAttach(PIN_VIS_SANS_FIN, 5000, 8);

  dht.begin();

  // Configuration WiFi et MQTT
  configurer_wifi_mqtt();

  xTaskCreatePinnedToCore(task_grafcet, "graf", 4096, NULL, 3, NULL, 1);
  xTaskCreatePinnedToCore(task_sensors, "sens", 4096, NULL, 2, NULL, 1);
  xTaskCreatePinnedToCore(task_lcd,     "lcd",  4096, NULL, 1, NULL, 1);
  xTaskCreatePinnedToCore(task_mqtt,    "mqtt", 4096, NULL, 1, NULL, 0);

  delay(1000);
  lcd.clear();
  lcd.print("READY");
}

// ================= LOOP =================
void loop() {
  vTaskDelay(pdMS_TO_TICKS(1000));
}

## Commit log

2026-09-27 Rebuild repository structure from project source and thesis
    Reorganizes the project into the documented layout (docs/, firmware/,
    hardware/, mechanical/, cloud/, media/, research/), populating each
    folder from the mechanical CAD, KiCad PCB, ESP32 firmware, cloud
    applications and academic thesis. Documentation in docs/*.md is
    written from the thesis content. Secrets (.env, serviceAccountKey.json) are excluded via .gitignore.
    [#sechageDDD.DXF, 12 V_9 A_Battery.SLDPRT, 12 V_9 Ah_20h _6FM-9 Lead-Acid Battery.SLDASM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]
2026-09-27 Trim mechanical/solidworks to the final assembly only
    Repository is public: drop the per-part native SolidWorks source
    (blocs 1-4, chassir, composant_electronique, boitier_3D, assets) and
    keep only Smart-Soja.STEP, the neutral final assembly export.
    [#sechageDDD.DXF, 12 V_9 A_Battery.SLDPRT, 12 V_9 Ah_20h _6FM-9 Lead-Acid Battery.SLDASM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]
2026-09-27 Add logo, badges and hero image to README
    Adds a centered header with project logo, shields.io badges (license,
    status, platform, tech stack, live repo size/last-commit) and a hero
    shot of the assembled prototype, plus a lightweight footer.
2026-09-27 Remove mechanical/solidworks/Smart-Soja.STEP (87.7 MB)
    Renders and drawings already cover the mechanical design visually;
    CAD source files are available on request instead of being carried
    in the public repo. Adds a note explaining how to get them.
2026-09-27 chmod: update file permissions for ESP32 firmware scripts
2026-09-27 Fix CAD source contact link after authorship update
2026-09-27 Prevent large SolidWorks CAD sources from re-entering the repository

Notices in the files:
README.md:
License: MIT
